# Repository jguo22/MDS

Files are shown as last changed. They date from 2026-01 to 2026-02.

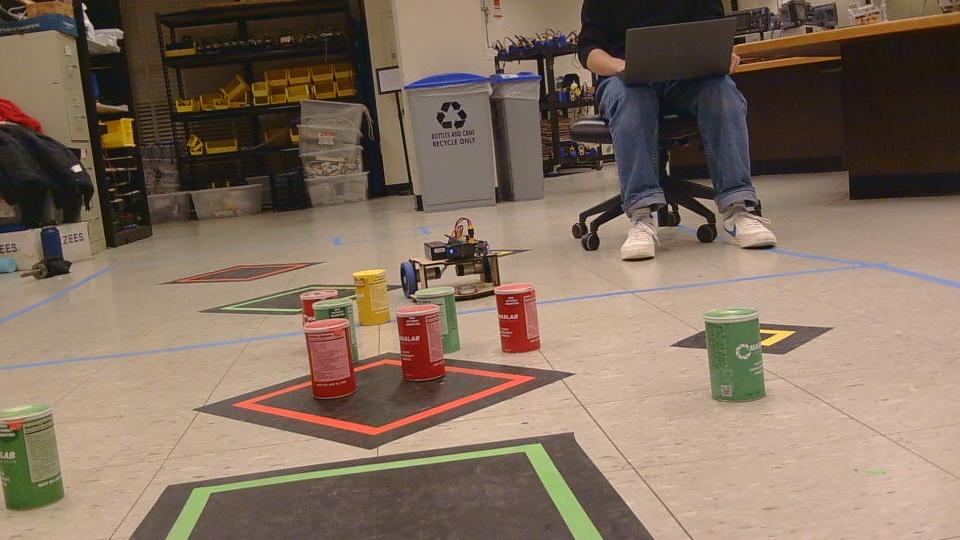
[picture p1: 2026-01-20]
vision/test2.jpg

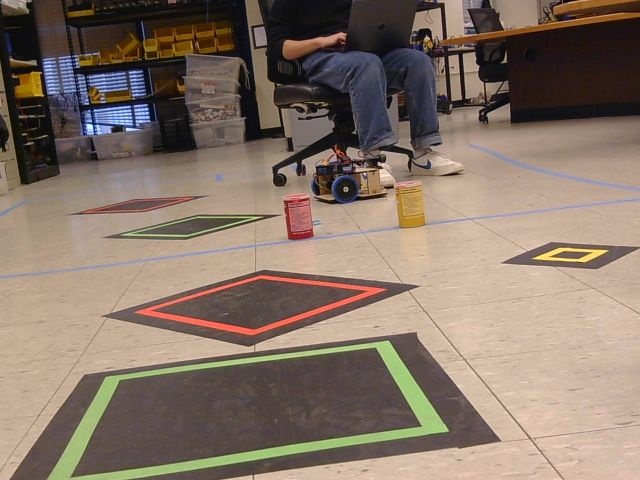
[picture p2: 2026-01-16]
vision/test.jpg

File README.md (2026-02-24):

# MASLAB 2026 Autonomous Robot
https://maslab.mit.edu/2026/wiki/team02

Autonomous can-collecting robot for the MIT MASLAB 2026 competition. Features dual-camera vision, YOLOv11 segmentation, path planning with Theta*, and a distributed architecture with Pi-side execution and computer-side control.

## Architecture

```
┌─────────────────────────────────────────────────────────────────────┐
│                          Computer                                    │
│  ┌─────────────────┐    ┌──────────────────┐    ┌────────────────┐  │
│  │ ComputerReceiver│◄───│  RobotHandler    │◄───│ Vision (YOLO)  │  │
│  │ (video in,      │    │  State Machine   │    │ Segmentation   │  │
│  │  commands out)  │    │  + Theta* Path   │    │ + Pixel-to-3D  │  │
│  └────────┬────────┘    └──────────────────┘    └────────────────┘  │
│           │                                                          │
│           │ TCP (video: 5000, commands: 5001)                        │
│           ▼                                                          │
│  ┌─────────────────┐                                                 │
│  │RemoteRobotCmd   │ ◄── IRobotCommander interface                   │
│  └─────────────────┘                                                 │
└─────────────────────────────────────────────────────────────────────┘
                              │
                              │ Network
                              ▼
┌─────────────────────────────────────────────────────────────────────┐
│                        Raspberry Pi                                  │
│  ┌─────────────────┐    ┌──────────────────┐    ┌────────────────┐  │
│  │  PiStreamer     │───►│ DirectRobotCmd   │───►│ Nav + Raven    │  │
│  │  (video out,    │    │ (local execution)│    │ Motor Control  │  │
│  │   commands in)  │    └──────────────────┘    └────────────────┘  │
│  └─────────────────┘                                                 │
│           │                                                          │
│           ▼                                                          │
│  ┌─────────────────┐    ┌──────────────────┐                        │
│  │  Dual Cameras   │    │  IMU + Distance  │                        │
│  │  (top + bottom) │    │  Sensors         │                        │
│  └─────────────────┘    └──────────────────┘                        │
└─────────────────────────────────────────────────────────────────────┘
```

## Quick Start

### Computer Side
```bash
# Install dependencies
pip install -e .

# Run computer receiver (waits for Pi connection)
python main_comp.py
```

### Pi Side
```bash
# Install dependencies
pip install -e .

# Run Pi streamer (auto-reconnects to computer)
python main_pi.py --camera-top /dev/videoblacktop --camera-bottom /dev/videoblackbot
```

## Project Structure

```
MDS/
├── main_comp.py              # Computer entry point (receiver + vision + state machine)
├── main_pi.py                # Pi entry point (streamer + command execution)
│
├── IRobotCommander.py        # Abstract interface for robot commands
├── RemoteRobotCommander.py   # Network implementation (computer side)
├── DirectRobotCommander.py   # Direct execution (Pi side)
│
├── RobotHandler.py           # Full state machine with zone/can tracking
├── RobotHandler_Simple.py    # Simplified state machine for basic collection
│
├── thetaStar.py              # Theta* path planning with obstacle avoidance
├── nav.py                    # Navigation controller (IMU + odometry)
├── navHelpers.py             # Movement command generators
│
├── raven.py                  # Raven motor controller driver
├── RavenWrapper.py           # High-level Raven interface (gripper, elevator)
├── IMUWrapper.py             # BNO08x IMU wrapper
├── distanceSensorWrapper.py  # Distance sensor for can approach
│
├── config.py                 # Robot configuration constants
├── colors.py                 # YOLO class names and color constants
├── getPickedCanColor.py      # Detect color of can in gripper
│
├── connection/               # Network communication
│   ├── ComputerReceiver.py   # Computer-side video receiver + command sender
│   ├── PiStreamer.py         # Pi-side video streamer + command receiver
│   ├── RemoteRobotCommander.py # Network command implementation
│   ├── protocol.py           # TCP message framing
│   ├── message_types.py      # Command type constants
│   ├── CameraCapture.py      # Camera interface
│   ├── FrameSaver.py         # Auto-save frames for debugging
│   └── frame_info.py         # Frame metadata structure
│
└── vision/                   # Vision processing (refactored)
    ├── segment.py            # YOLO segmentation entry point
    ├── mask_utils.py         # Mask processing (convex hull, HSV refinement)
    ├── can_utils.py          # Can detection + pixel-to-world transform
    ├── zone_utils.py         # Zone detection + quad extraction
    ├── pixelTo3D.py          # Camera calibration + ground plane projection
    ├── relativeCoordinates.py # SE2 coordinate transformations
    ├── calibration/          # Camera calibration tools
    ├── train/                # YOLO training scripts and datasets
    ├── best.pt               # Trained YOLO model
    └── yolo11n.pt            # Pretrained YOLO model
```

## Vision System

### YOLO Segmentation

Custom YOLOv11n model trained on 8 classes:
- `Boundary` (0), `Golden Can` (1), `Golden Zone` (2)
- `Green Can` (3), `Green Zone` (4), `Red Can` (5), `Red Zone` (6), `Robot` (7)

```python
from vision.segment import segmentImage
from vision.can_utils import getCans
from vision.zone_utils import getZones

result = segmentImage(image)  # Run YOLO segmentation
cans, can_classes = getCans(result, image, is_top=True)  # Get can positions (mm)
zones, zone_classes = getZones(result, image, is_top=True)  # Get zone quads (mm)
```

### Pixel-to-World Transformation

Transforms pixel coordinates to ground plane (mm) using camera calibration:

```python
from vision.pixelTo3D import transform_uv_to_xy

# pixel (u, v) -> world (x, y) in mm
x, y = transform_uv_to_xy(pixel_x, pixel_y, is_top=True)
```

### Coordinate Transformations

SE2-based world/relative coordinate conversion:

```python
from spatialmath import SE2
from vision.relativeCoordinates import world_to_relative, relative_to_world

robot_pose = SE2(robot_x, robot_y, robot_heading)
local_x, local_y = world_to_relative(world_point, robot_pose)
world_x, world_y = relative_to_world(local_point, robot_pose)
```

### Gripper Can Detection

Detect which color can is currently in the gripper:

```python
from getPickedCanColor import getPickedUpCanColor

color = getPickedUpCanColor(result, image)  # Returns 'Green Can', 'Red Can', etc.
```

## Robot Commander Interface

All robot commands go through `IRobotCommander`, with two implementations:

| Method | Description |
|---|---|
| `override_movement(args)` | Raw motor commands `[left, right, ticks, ...]` |
| `override_waypoints(args)` | Navigate through waypoints `[x1, y1, x2, y2, ...]` |
| `override_relative_xy(x, y)` | Move relative to robot (mm) |
| `override_world_xy(x, y)` | Navigate to world coordinates (mm) |
| `pickup_can()` | Close gripper + raise elevator |
| `set_down_can()` | Lower elevator + open gripper |
| `open_gripper()` | Open gripper only |
| `lower_elevator()` | Lower elevator only |
| `approach_can_with_ds()` | Approach can using distance sensor |
| `backup()` | Back up short distance |
| `stack(temp, stack, count)` | Stack can at position |
| `waitFinishedMoving()` | Block until movement complete |

## State Machines

### RobotHandler (Full)
Complex state machine with:
- Zone confidence tracking
- Can detection grid with thresholds
- Opponent zone avoidance
- Full early game strategy

### RobotHandler_Simple (Simplified)
Basic can collection:
```
SearchForCan -> MoveToCan -> ApproachingCan -> GrabCan -> MoveToZone -> Done
```

Configuration:
- `MAX_STACK`: Number of cans to collect before going to zone
- `target_zone`: Which zone to deliver to (GREEN_ZONE, RED_ZONE, GOLDEN_ZONE)
- `target_can_color`: Which color cans to collect

## Hardware

### Raven Motor Controller
Custom serial motor controller (460800 baud):
- 5 motor channels, 4 servo channels
- Position/velocity PID control
- Built-in odometry

### IMU (BNO08x)
- Must initialize before Raven board
- Heading relative to startup position

### Distance Sensor
- Used for precise can approach
- Target distance: 25mm, Max detection: 500mm

## Network Protocol

TCP-based with custom framing:
- Video port: 5000 (JPEG frames)
- Command port: 5001 (typed messages with float arrays)

Message types defined in `connection/message_types.py`:
```python
OVERRIDE_MOVEMENTS = 2      # [left, right, ticks, ...]
OVERRIDE_WAYPOINTS = 3      # [x1, y1, x2, y2, ...]
PICKUP_CAN = 4              # No args
RELEASE_CAN = 5             # No args
APPROACH_CAN_DS = 9         # No args
OPEN_GRIPPER = 15           # No args
LOWER_ELEVATOR = 16         # No args
# ... and more
```

## Configuration

Key constants in `config.py`:
```python
FRAME_WIDTH = 640
FRAME_HEIGHT = 480
FPS = 30

CAN_DIAMETER = 76.2         # mm
ROBOT_DIAMETER = 300        # mm
CLAW_OFFSET = 150           # mm from robot center
APPROACH_OFFSET = 200       # mm approach distance
```

## Development

### Testing Vision
```bash
# Test segmentation on image
python vision/segment.py

# Test can detection
python getPickedCanColor.py
```

### Training YOLO
```bash
cd vision/train
python train.py
```

### Debugging
- Frames auto-saved to `images/` with cooldown
- Telemetry streamed via `Streamer` class
- Profile data saved to `profiles/`

## Dependencies

See `pyproject.toml`:
- ultralytics (YOLO)
- opencv-python
- numpy
- spatialmath-python
- shapely
- adafruit-circuitpython-bno08x (Pi only)
- pyserial (Pi only)

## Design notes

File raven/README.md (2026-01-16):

# raven
Robot Hardware Controller

## Pcb
Color pallet works best with KiCad wDark theme

## Firmware
Built using cmake and all dependencies exist locally

Install build tools if you need to
```
sudo apt install ninja-build cmake gcc-arm-none-eabi
```

### Compiling
Compile from motor-hub folder
```
cmake . --preset=Release
cd Release
ninja
```

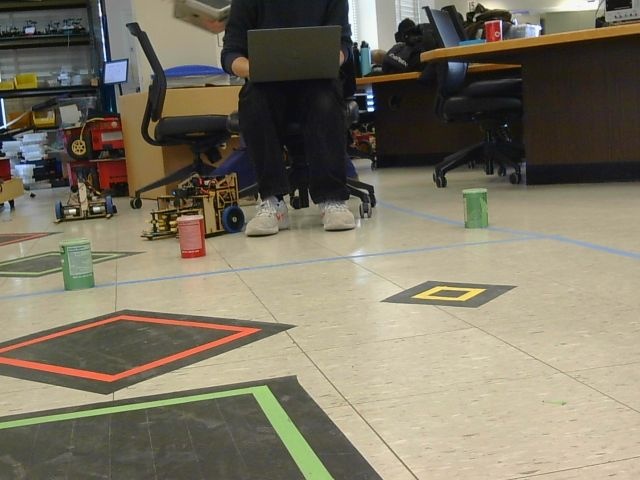
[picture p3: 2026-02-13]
images/frame_20260123_130812_1769191692037.jpg

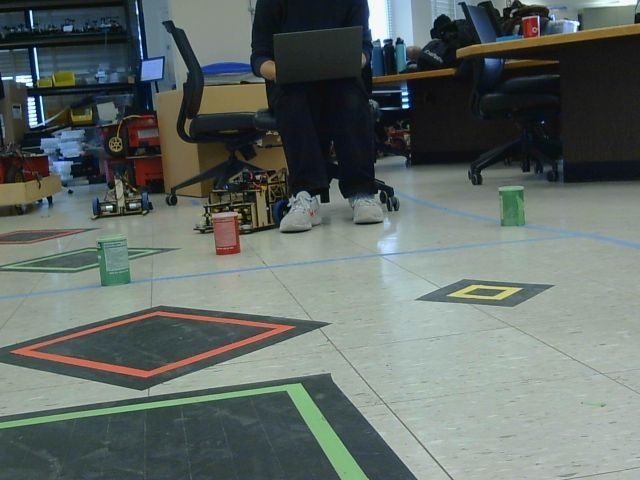
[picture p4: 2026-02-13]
images/frame_20260123_130701_1769191621960.jpg

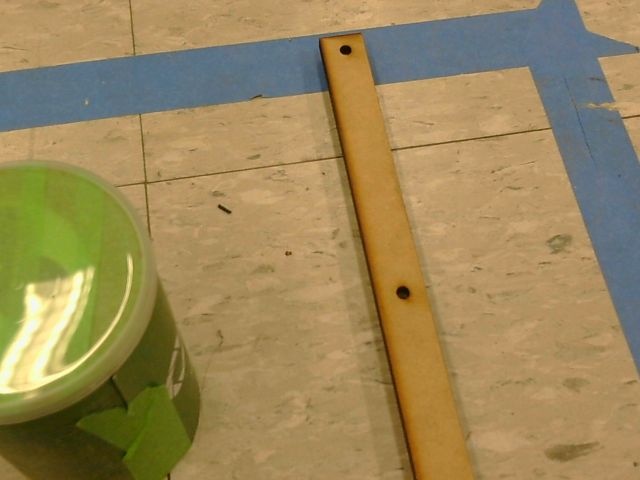
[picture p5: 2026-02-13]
images/frame_20260123_111651_1769185011692.jpg

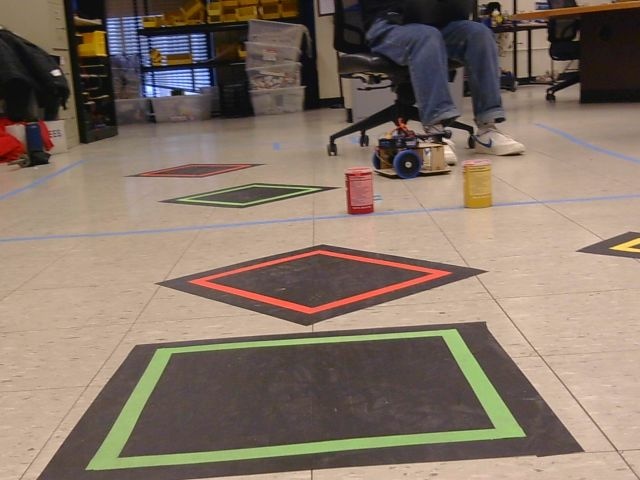
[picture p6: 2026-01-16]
images/frame_20260114_160316_1768424596912.jpg

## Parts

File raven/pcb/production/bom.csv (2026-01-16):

Designator | Footprint | Quantity | Value | LCSC Part #
C1 | C_Elec_8x6.2 | 1 | 100u | C178539
C10, C18, C30, C31, C34, C35, C36, C39, C7, C8 | 0402 | 10 | 100n | C1525
C11, C44 | 0402 | 2 | 220n | C16772
C12 | 0603 | 1 | 4u7 | C19666
C13, C50, C51, C52, C53, C54, C57, C58, C59, C60, C61, C62, C63, C64, C65 | 0805 | 15 | 22u | C45783
C14, C16, C19, C2, C21, C24, C26, C4, C66, C68 | 0402 | 10 | 100n | C307331
C15, C20, C25, C3, C6, C67, C9 | 0402 | 7 | 2u2 | C12530
C17, C22, C27, C5, C69 | 0402 | 5 | 22n | C1532
C23 | 0603 | 1 | 100n | C14663
C28 | 0603 | 1 | 10u | C96446
C32, C33 | 0402 | 2 | 12p | C1547
C37, C38, C46, C47, C48, C49 | 0402 | 6 | 1u | C52923
C40, C41, C42, C43 | 1206 | 4 | 47u | C96123
C45 | 0805 | 1 | 2u2 | C377773
C55 | 0402 | 1 | 10u | C15525
D1, D12, D14, D27, D3, D6, D9 | 0603 | 7 | GLED | C72043
D10, D13, D28, D4, D7 | 0603 | 5 | RLED | C2286
D11, D2, D26, D5, D8 | 0603 | 5 | WLED | C2290
F1 | 1206 | 1 | Fuse | C2838917
FB1 | 0805 | 1 | FerriteBead | C1017
J2, J5 | JST_SH_SM04B-SRSS-TB_1x04-1MP_P1.00mm_Horizontal | 2 | Conn_01x04_MountingPin | C160404
L1 | L_0660A | 1 | 1u | C18199443
Q1 | SOT-23 | 1 | AO3400A | C20917
Q3 | DMP2002UPS | 1 | DMP2002UPS | C154869
R1, R10, R11, R12, R13, R14, R15, R16, R17, R18, R19, R2, R20, R21, R22, R23, R27, R3, R4, R5, R50, R59, R6, R60, R61, R62, R63, R9 | 0402 | 28 | 1k | C11702
R24 | 0402 | 1 | 33k | C25779
R25, R26, R28, R29, R31, R33, R34, R35, R37, R39, R40, R41, R43, R49, R51, R52, R54, R55, R66, R7, R8 | 0402 | 21 | 7k5 | C25918
R53, R57 | 0402 | 2 | 56k | C25796
R56 | 0402 | 1 | 47k | C25792
R58 | 0402 | 1 | 100k | C25741
SW1, SW2 | TS-1088 | 2 | SW_Push | C720477
U1, U30, U4, U5, U6 | HTSSOP-16-1EP_4.4x5mm_P0.65mm_EP3.4x5mm_Mask2.46x2.31mm | 5 | DRV8874PWPR | C1855818
U2 | LGA-14_3x2.5mm_P0.5mm_LayoutBorder3x4y | 1 | ICM-42688-P | C1850418
U7 | QFN-48-1EP_7x7mm_P0.5mm_EP5.6x5.6mm | 1 | STM32G431CBUx | C529356
U8 | SOIC-16_3.9x9.9mm_P1.27mm | 1 | 74HC595 | C5947
U9 | TPS548B28RWWR | 1 | TPS548B28RWWR | C3188716
Y1 | Crystal_SMD_3225-4Pin_3.2x2.5mm | 1 | 16MHz | C13738

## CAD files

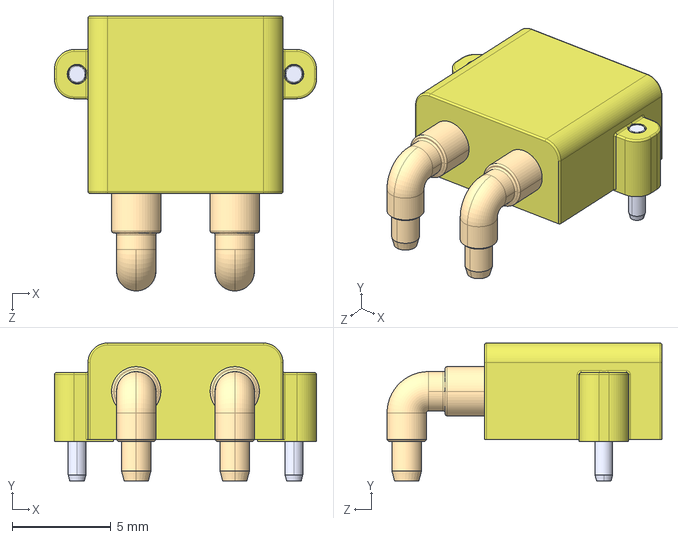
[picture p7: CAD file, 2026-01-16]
raven/pcb/3dmodels/XT30PW-M.STEP
13.3 x 7.00 x 14.0 mm

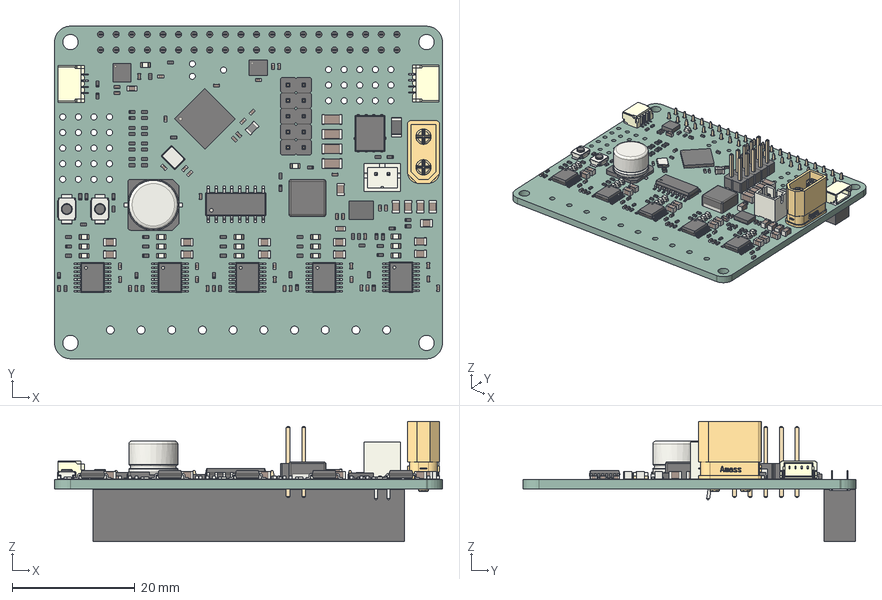
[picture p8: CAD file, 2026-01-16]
raven/pcb/raven.step
63.2 x 54.2 x 19.6 mm
L_Changjiang_FNR6028S
R_0402_1005Metric x 63
C_0402_1005Metric x 43
SOIC_16_39x99mm_P127mm
User Library-xt30upb-m
LED_0603_1608Metric x 17
PinHeader_1x02_P254mm_Vertical x 5
LGA_14_3x25mm_P05mm_LayoutBorder3x4y
C_0805_2012Metric x 16
C_1206_3216Metric x 4
C_0603_1608Metric x 2
QSOP_16_39x49mm_P0635mm x 5
Fuse_1206_3216Metric
LGA_16_3x3mm_P05mm
SM04B-SRSS-TB(LF)(SN) x 2
Crystal_SMD_3225-4Pin_3.2x2.5mm
SW_SPST_B3U-1000P-B x 2
RWW0021A_ASM
L_0805_2012Metric
Vishay_PowerPAK_SO-8
QFN-48-1EP_7x7mm_Pitch0.5mm
C_Elec_8x62
JST_B2B_PH_K
PinSocket_2x20_P2.54mm_Vertical
raven_PCB

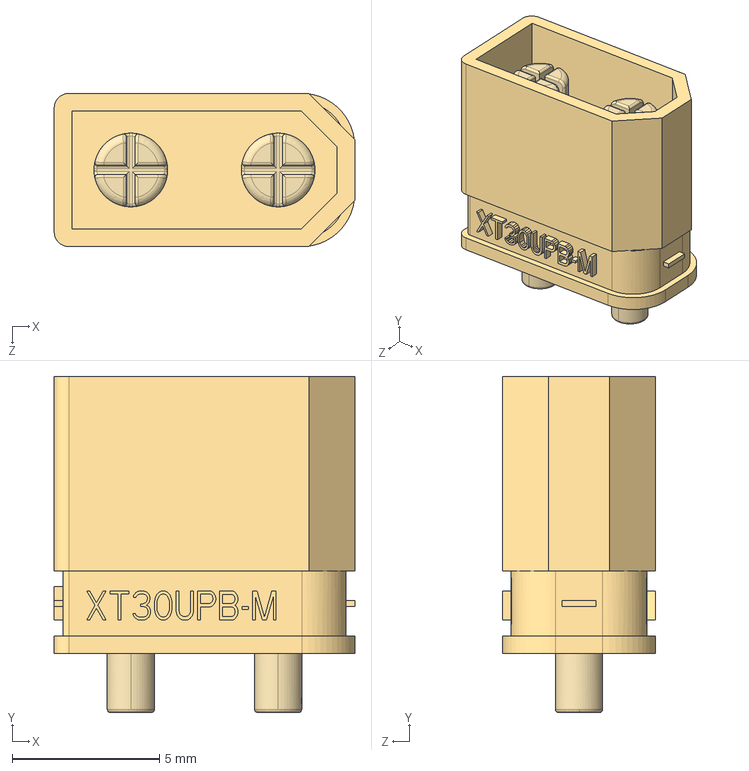
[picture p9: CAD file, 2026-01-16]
raven/pcb/3dmodels/XT30UPB-M.STEP
10.2 x 11.4 x 5.20 mm
XT30UPB-M
XT30UPB-M-PIN x 2

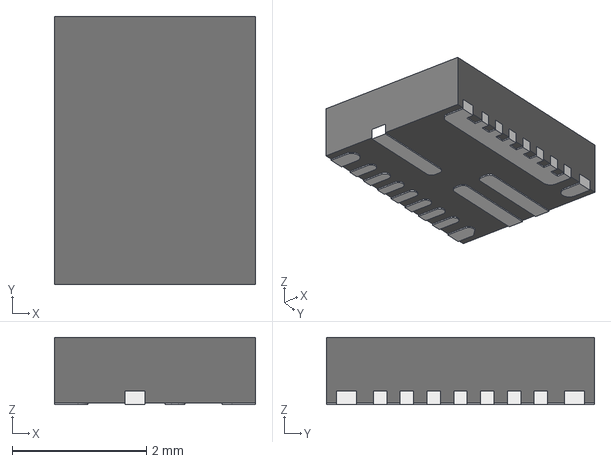
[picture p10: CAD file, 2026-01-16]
raven/pcb/3dmodels/RWW0021A.STEP
3.00 x 4.00 x 1.00 mm
FRAME
MOLD

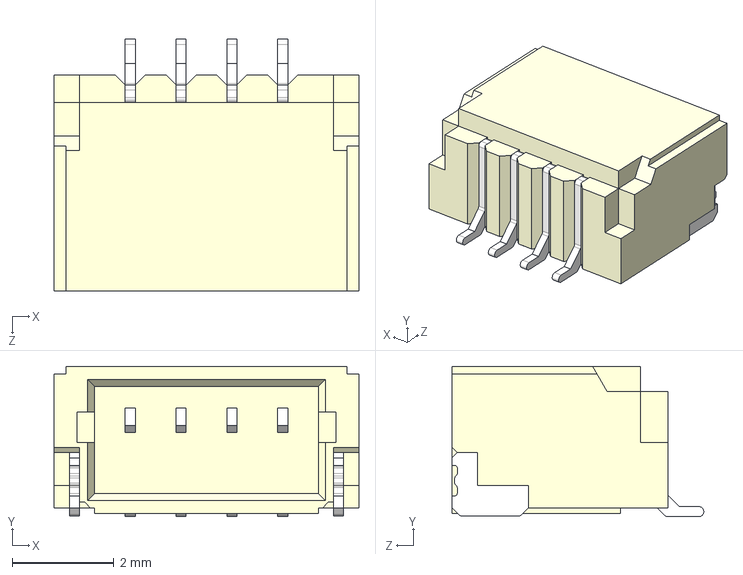
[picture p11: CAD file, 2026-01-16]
raven/pcb/3dmodels/SM04B-SRSS-TB.STEP
6.00 x 2.96 x 4.95 mm

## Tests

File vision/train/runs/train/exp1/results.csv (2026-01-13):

epoch | time | train/box_loss | train/cls_loss | train/dfl_loss | metrics/precision(B) | metrics/recall(B) | metrics/mAP50(B) | metrics/mAP50-95(B) | val/box_loss | val/cls_loss | val/dfl_loss | lr/pg0 | lr/pg1 | lr/pg2
1 | 5.62403 | 0.70651 | 3.71754 | 0.99922 | 0.00399 | 0.61548 | 0.04409 | 0.02615 | 0.58543 | 3.50993 | 0.94233 | 0.0002 | 0.0002 | 0.0002
2 | 11.2085 | 0.60502 | 3.71149 | 0.94844 | 0.00429 | 0.65714 | 0.05756 | 0.03691 | 0.48434 | 3.47711 | 0.91924 | 0.000499984 | 0.000499984 | 0.000499984
3 | 16.8646 | 0.61432 | 3.49701 | 0.9548 | 0.00459 | 0.69881 | 0.10148 | 0.07609 | 0.42329 | 3.44849 | 0.90228 | 0.000799947 | 0.000799947 | 0.000799947
4 | 22.1051 | 0.63108 | 3.55089 | 0.98978 | 0.00514 | 0.7881 | 0.1724 | 0.1499 | 0.47095 | 3.42675 | 0.9275 | 0.00109989 | 0.00109989 | 0.00109989
5 | 27.1586 | 0.55508 | 3.48892 | 0.91688 | 0.00492 | 0.74881 | 0.16782 | 0.14527 | 0.45083 | 3.40929 | 0.89888 | 0.00139982 | 0.00139982 | 0.00139982
6 | 32.1116 | 0.53779 | 3.28165 | 0.92975 | 0.00577 | 0.87143 | 0.17461 | 0.15685 | 0.4217 | 3.38585 | 0.88139 | 0.00169972 | 0.00169972 | 0.00169972
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

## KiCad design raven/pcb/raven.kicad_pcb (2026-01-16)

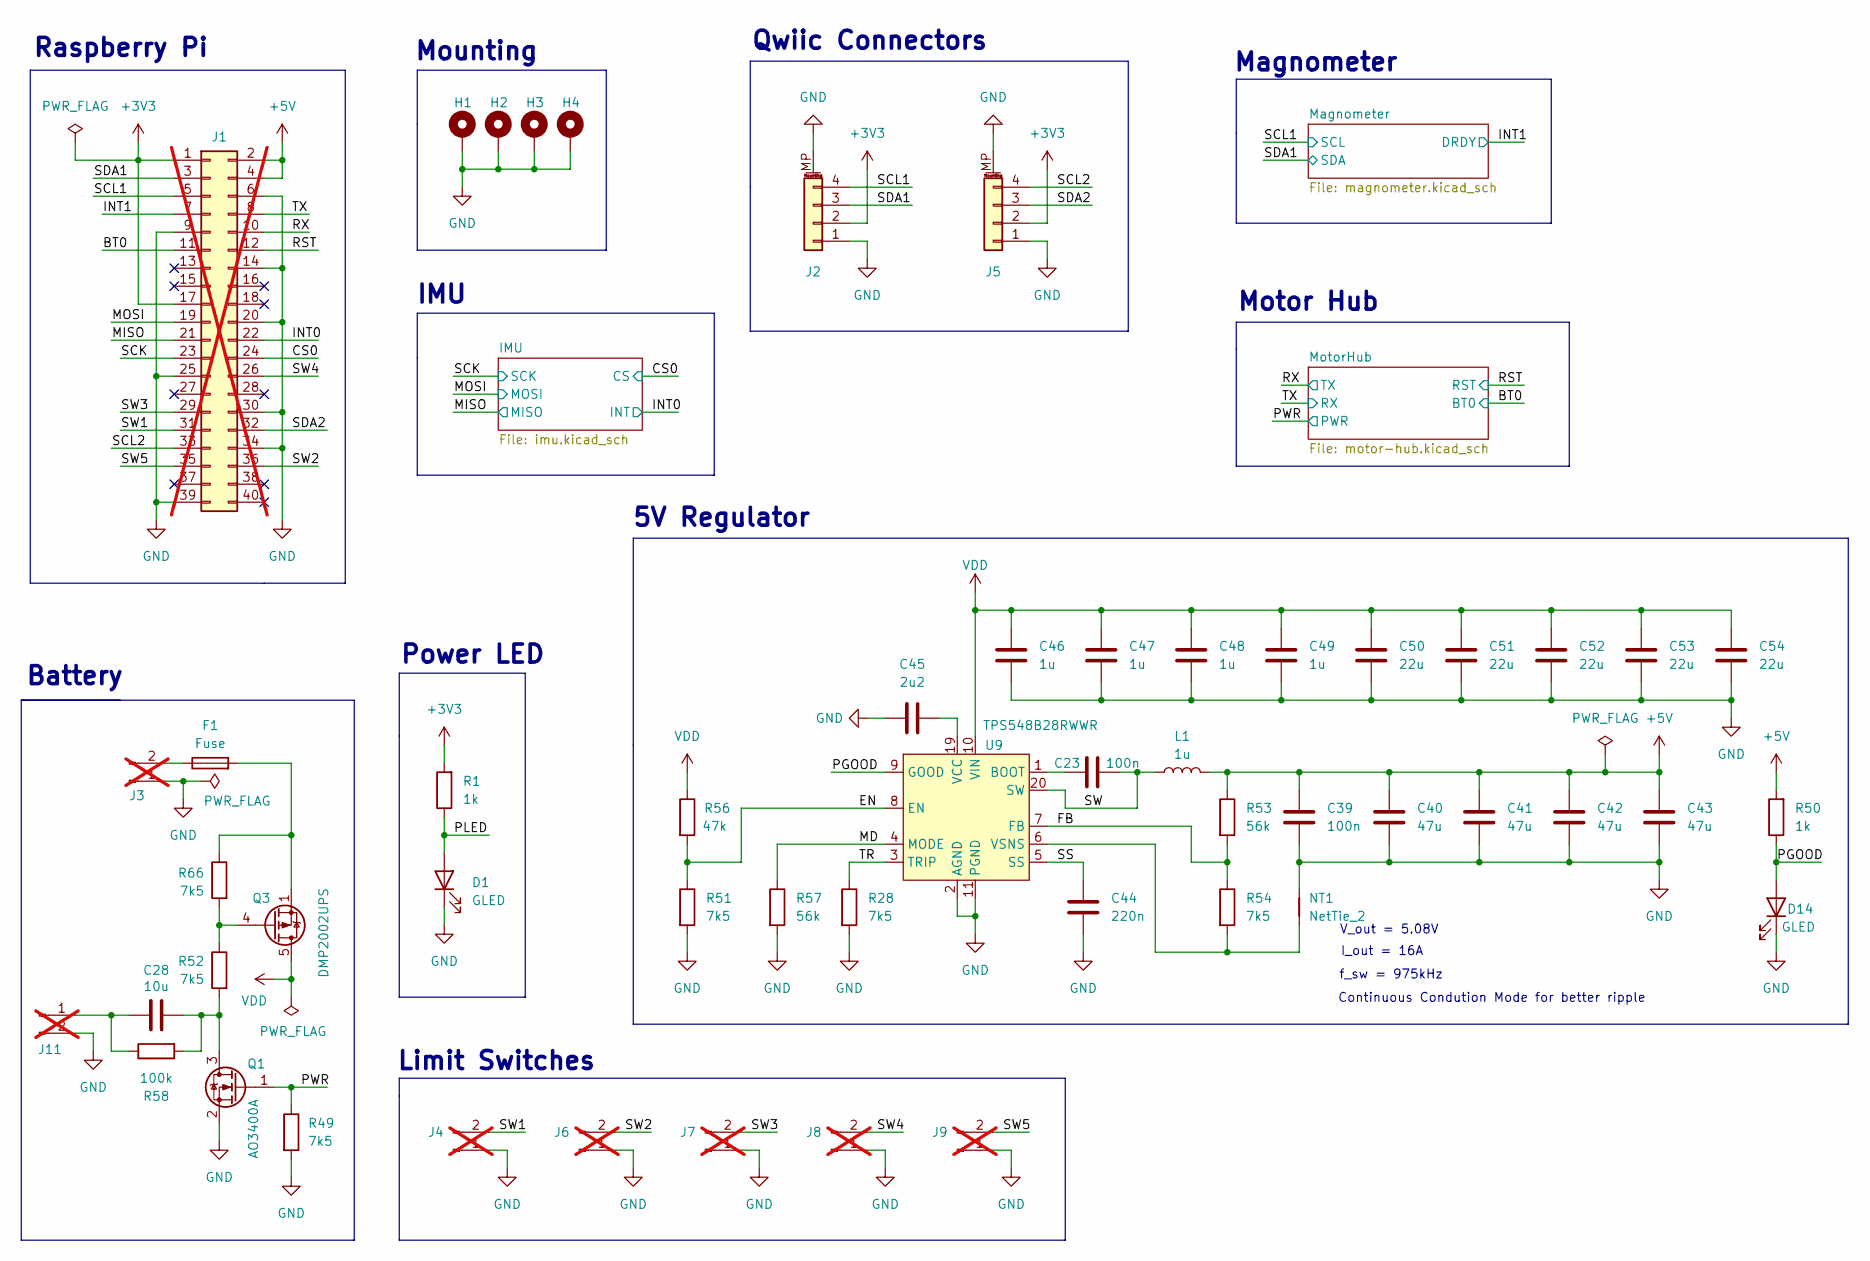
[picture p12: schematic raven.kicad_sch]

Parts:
C23: 100n; C_0603_1608Metric; LCSC C14663
C28: 10u; C_0603_1608Metric; LCSC C96446
C39: 100n; C_0402_1005Metric; LCSC C1525
C40, C41, C42, C43: 47u; C_1206_3216Metric; LCSC C96123
C44: 220n; C_0402_1005Metric; LCSC C16772
C45: 2u2; C_0805_2012Metric; LCSC C377773
C46, C47, C48, C49: 1u; C_0402_1005Metric; LCSC C52923
C50, C51, C52, C53, C54: 22u; C_0805_2012Metric; LCSC C45783
D1, D14: GLED; LED_0603_1608Metric; LCSC C72043
F1: Fuse; Fuse_1206_3216Metric; LCSC C2838917
H1, H2, H3, H4: MountingHole_Pad; MountingHole_2.5mm_Pad
J1: Conn_02x20_Odd_Even; PinSocket_2x20_P2.54mm_Vertical; LCSC C35165; not fitted
J2, J5: Conn_01x04_MountingPin; JST_SH_SM04B-SRSS-TB_1x04-1MP_P1.00mm_Horizontal; LCSC C160404
J3: Conn_01x02_Pin; AMASS_XT30UPB-M_1x02_P5.0mm_Vertical; LCSC C428721; not fitted
J4, J6, J7, J8, J9: Conn_01x02_Pin; PinHeader_1x02_P2.54mm_Vertical; LCSC C492401; not fitted
J11: Conn_01x02_Pin; JST_PH_B2B-PH-K_1x02_P2.00mm_Vertical; LCSC C131337; not fitted
L1: 1u; L_0660A; LCSC C18199443
NT1: NetTie_2; NetTie-2_SMD_Pad0.5mm
Q1: AO3400A; SOT-23; LCSC C20917
Q3: DMP2002UPS; LCSC C154869
R1, R50: 1k; R_0402_1005Metric; LCSC C11702
R28, R49, R51, R52, R54, R66: 7k5; R_0402_1005Metric; LCSC C25918
R53, R57: 56k; R_0402_1005Metric; LCSC C25796
R56: 47k; R_0402_1005Metric; LCSC C25792
R58: 100k; R_0402_1005Metric; LCSC C25741
U9: TPS548B28RWWR; LCSC C3188716

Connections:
+3V3: J1.1, J1.17, J2.2, J5.2, R1.2; also elsewhere on the board
+5V: C39.2, C40.1, C41.1, C42.1, C43.1, J1.2, J1.4, L1.2, R50.2, R53.1; also elsewhere on the board
/BT0: J1.11; also elsewhere on the board
/CS0: J1.24; also elsewhere on the board
/EN: R51.1, R56.2, U9.8 (EN)
/FB: R53.2, R54.1, U9.7 (FB)
/INT0: J1.22; also elsewhere on the board
/INT1: J1.7; also elsewhere on the board
/MD: R57.1, U9.4 (MODE)
/MISO: J1.21; also elsewhere on the board
/MOSI: J1.19; also elsewhere on the board
/PGOOD: D14.2 (A), R50.1, U9.9 (GOOD)
/PLED: D1.2 (A), R1.1
/PWR: Q1.1 (G), R49.1; also elsewhere on the board
/RST: J1.12; also elsewhere on the board
/RX: J1.10; also elsewhere on the board
/SCK: J1.23; also elsewhere on the board
/SCL1: J1.5, J2.4; also elsewhere on the board
/SCL2: J1.33, J5.4
/SDA1: J1.3, J2.3; also elsewhere on the board
/SDA2: J1.32, J5.3
/SS: C44.1, U9.5 (SS)
/SW: C23.2, L1.1, U9.20 (SW)
/SW1: J1.31, J4.2
/SW2: J1.36, J6.2
/SW3: J1.29, J7.2
/SW4: J1.26, J8.2
/SW5: J1.35, J9.2
/TR: R28.1, U9.3 (TRIP)
/TX: J1.8; also elsewhere on the board
GND: C39.1, C40.2, C41.2, C42.2, C43.2, C44.2, C45.1, C46.2, C47.2, C48.2, C49.2, C50.2, C51.2, C52.2, C53.2, C54.2, D1.1 (K), D14.1 (K), H1.1, H2.1, H3.1, H4.1, J1.6, J1.9, J1.14, J1.20, J1.25, J1.30, J1.34, J1.39, J2.1, J2.MP (MountPin), J3.1, J4.1, J5.1, J5.MP (MountPin), J6.1, J7.1, J8.1, J9.1, J11.2, NT1.1, Q1.2 (S), R28.2, R49.2, R51.2, R57.2, U9.2 (AGND), U9.11 (PGND), U9.12 (PGND), U9.13 (PGND), U9.14 (PGND), U9.15 (PGND), U9.16 (PGND), U9.17 (PGND), U9.18 (PGND); also elsewhere on the board
unnamed: F1.2, Q3.1 (S), Q3.2 (S), Q3.3 (S), R66.1
unnamed: F1.1, J3.2
unnamed: C28.1, J11.1, R58.1
unnamed: C28.2, Q1.3 (D), R52.2, R58.2
unnamed: Q3.4 (G), R52.1, R66.2
unnamed: C23.1, U9.1 (BOOT)
unnamed: C45.2, U9.19 (VCC)
unnamed: NT1.2, R54.2, U9.6 (VSNS)
VDD: C46.1, C47.1, C48.1, C49.1, C50.1, C51.1, C52.1, C53.1, C54.1, Q3.5 (D), Q3.6 (D), Q3.7 (D), Q3.8 (D), R56.1, U9.10 (VIN), U9.21 (VIN); also elsewhere on the board

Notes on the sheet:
Mounting
Power LED
5V Regulator
IMU
Motor Hub
V_out = 5.08V
Limit Switches
Continuous Condution Mode for better ripple
Qwiic Connectors
Battery
I_out = 16A
f_sw = 975kHz
Raspberry Pi
Magnometer

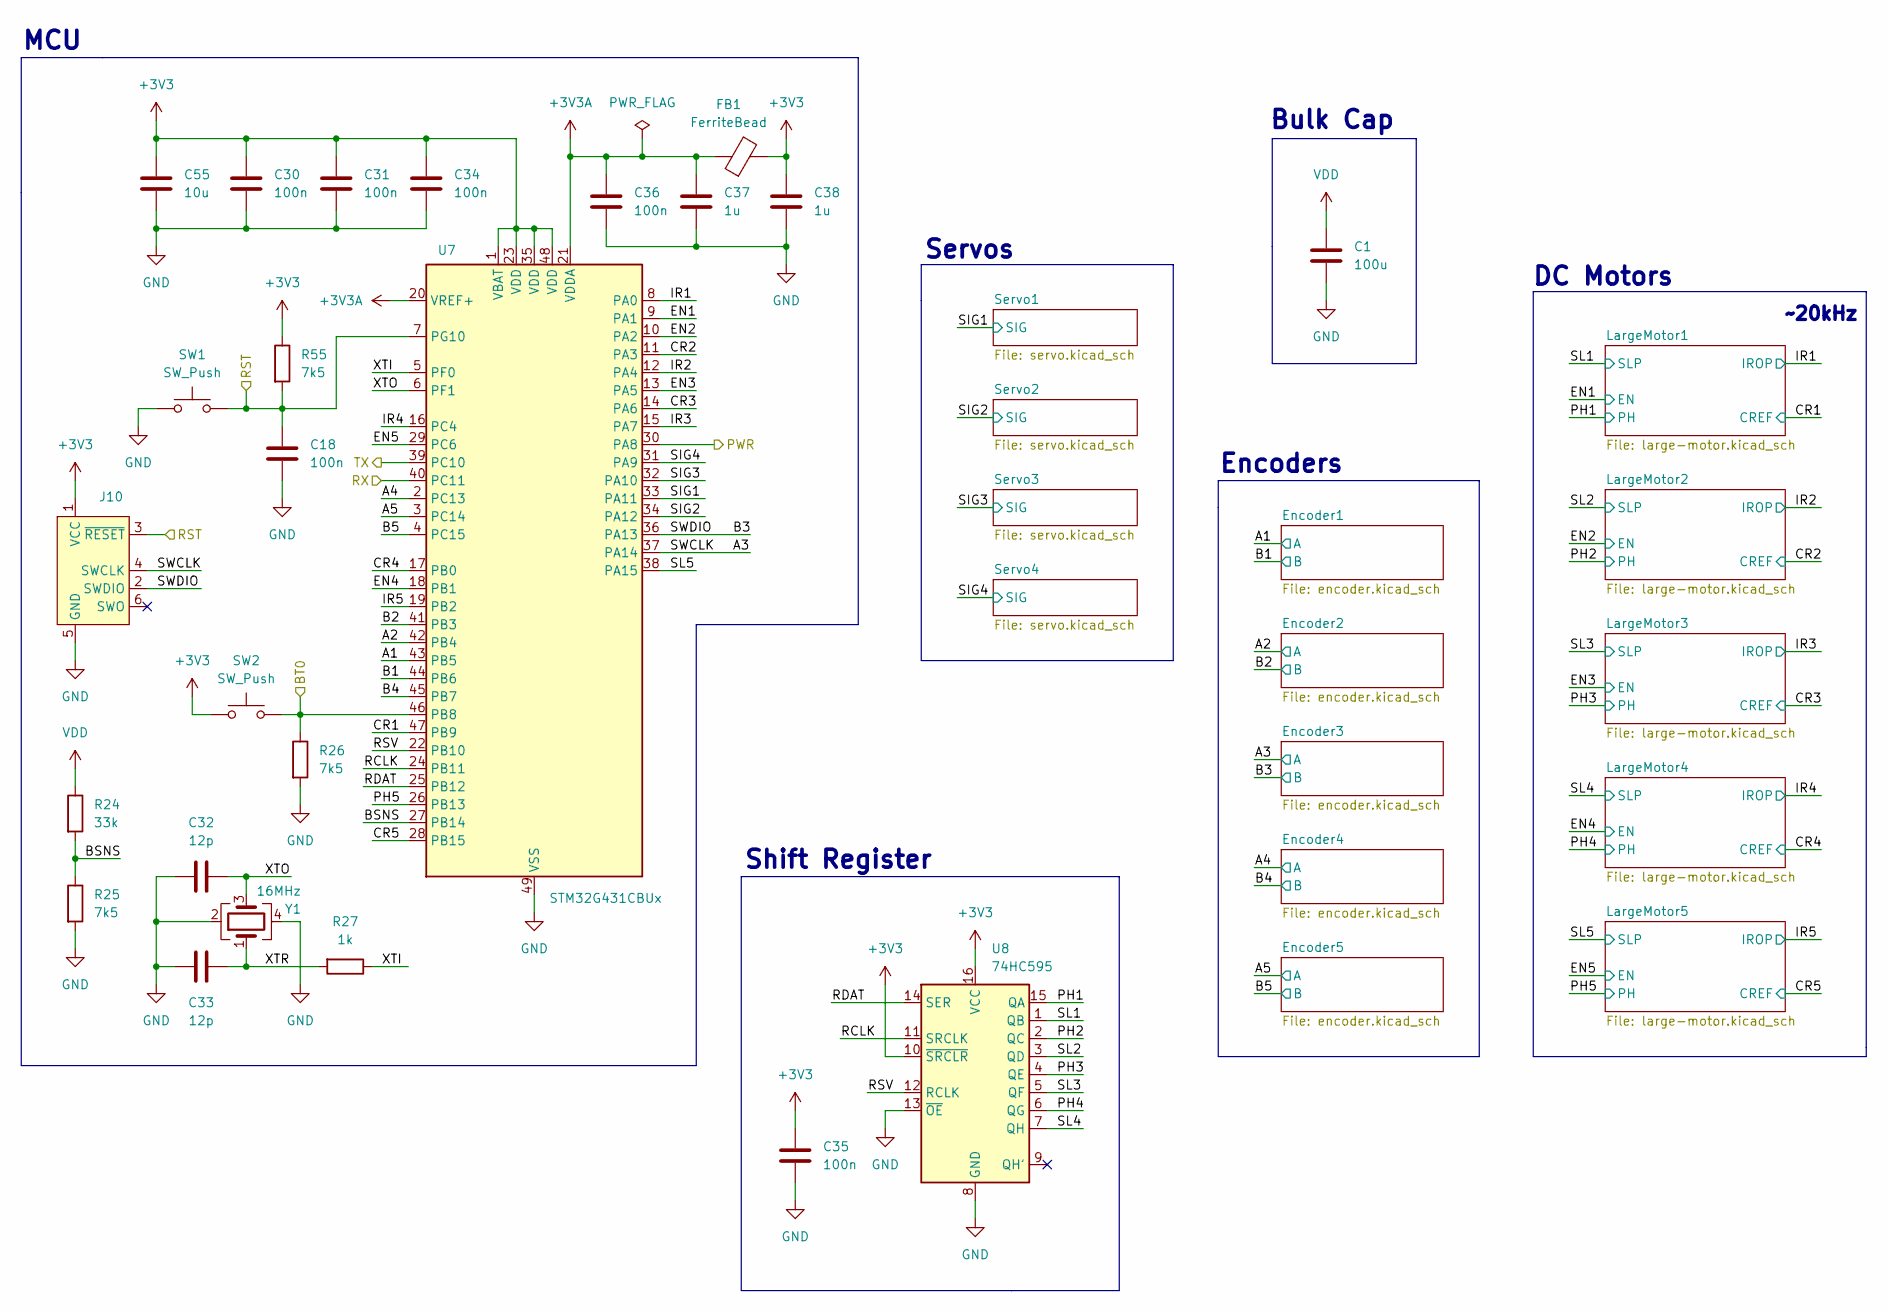
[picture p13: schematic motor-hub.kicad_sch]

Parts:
C1: 100u; C_Elec_8x6.2; LCSC C178539
C18, C30, C31, C34, C35, C36: 100n; C_0402_1005Metric; LCSC C1525
C32, C33: 12p; C_0402_1005Metric; LCSC C1547
C37, C38: 1u; C_0402_1005Metric; LCSC C52923
C55: 10u; C_0402_1005Metric; LCSC C15525
FB1: FerriteBead; L_0805_2012Metric; LCSC C1017
J10: Conn_ARM_SWD_TagConnect_TC2030-NL; Tag-Connect_TC2030-IDC-NL_2x03_P1.27mm_Vertical
R24: 33k; R_0402_1005Metric; LCSC C25779
R25, R26, R55: 7k5; R_0402_1005Metric; LCSC C25918
R27: 1k; R_0402_1005Metric; LCSC C11702
SW1, SW2: SW_Push; TS-1088; LCSC C720477
U7: STM32G431CBUx; QFN-48-1EP_7x7mm_P0.5mm_EP5.6x5.6mm; LCSC C529356
U8: 74HC595; SOIC-16_3.9x9.9mm_P1.27mm; LCSC C5947
Y1: 16MHz; Crystal_SMD_3225-4Pin_3.2x2.5mm; LCSC C13738

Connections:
+3V3: C30.1, C31.1, C34.1, C35.1, C38.1, C55.1, FB1.2, J10.1 (VCC), R55.1, SW2.1, U7.1 (VBAT), U7.23 (VDD), U7.35 (VDD), U7.48 (VDD), U8.10 (~SRCLR), U8.16 (VCC); also elsewhere on the board
+3V3A: C36.1, C37.1, FB1.1, U7.20 (VREF+), U7.21 (VDDA)
/BT0: R26.1, SW2.2, U7.46 (PB8); also elsewhere on the board
/MotorHub/A1: U7.43 (PB5); also elsewhere on the board
/MotorHub/A2: U7.42 (PB4); also elsewhere on the board
/MotorHub/A3: J10.4 (SWCLK), U7.37 (PA14); also elsewhere on the board
/MotorHub/A4: U7.2 (PC13); also elsewhere on the board
/MotorHub/A5: U7.3 (PC14); also elsewhere on the board
/MotorHub/B1: U7.44 (PB6); also elsewhere on the board
/MotorHub/B2: U7.41 (PB3); also elsewhere on the board
/MotorHub/B3: J10.2 (SWDIO), U7.36 (PA13); also elsewhere on the board
/MotorHub/B4: U7.45 (PB7); also elsewhere on the board
/MotorHub/B5: U7.4 (PC15); also elsewhere on the board
/MotorHub/BSNS: R24.2, R25.1, U7.27 (PB14)
/MotorHub/CR1: U7.47 (PB9); also elsewhere on the board
/MotorHub/CR2: U7.11 (PA3); also elsewhere on the board
/MotorHub/CR3: U7.14 (PA6); also elsewhere on the board
/MotorHub/CR4: U7.17 (PB0); also elsewhere on the board
/MotorHub/CR5: U7.28 (PB15); also elsewhere on the board
/MotorHub/EN1: U7.9 (PA1); also elsewhere on the board
/MotorHub/EN2: U7.10 (PA2); also elsewhere on the board
/MotorHub/EN3: U7.13 (PA5); also elsewhere on the board
/MotorHub/EN4: U7.18 (PB1); also elsewhere on the board
/MotorHub/EN5: U7.29 (PC6); also elsewhere on the board
/MotorHub/IR1: U7.8 (PA0); also elsewhere on the board
/MotorHub/IR2: U7.12 (PA4); also elsewhere on the board
/MotorHub/IR3: U7.15 (PA7); also elsewhere on the board
/MotorHub/IR4: U7.16 (PC4); also elsewhere on the board
/MotorHub/IR5: U7.19 (PB2); also elsewhere on the board
/MotorHub/PH1: U8.15 (QA); also elsewhere on the board
/MotorHub/PH2: U8.2 (QC); also elsewhere on the board
/MotorHub/PH3: U8.4 (QE); also elsewhere on the board
/MotorHub/PH4: U8.6 (QG); also elsewhere on the board
/MotorHub/PH5: U7.26 (PB13); also elsewhere on the board
/MotorHub/RCLK: U7.24 (PB11), U8.11 (SRCLK)
/MotorHub/RDAT: U7.25 (PB12), U8.14 (SER)
/MotorHub/RSV: U7.22 (PB10), U8.12 (RCLK)
/MotorHub/SIG1: U7.33 (PA11); also elsewhere on the board
/MotorHub/SIG2: U7.34 (PA12); also elsewhere on the board
/MotorHub/SIG3: U7.32 (PA10); also elsewhere on the board
/MotorHub/SIG4: U7.31 (PA9); also elsewhere on the board
/MotorHub/SL1: U8.1 (QB); also elsewhere on the board
/MotorHub/SL2: U8.3 (QD); also elsewhere on the board
/MotorHub/SL3: U8.5 (QF); also elsewhere on the board
/MotorHub/SL4: U8.7 (QH); also elsewhere on the board
/MotorHub/SL5: U7.38 (PA15); also elsewhere on the board
/MotorHub/XTI: R27.1, U7.5 (PF0)
/MotorHub/XTO: C32.2, U7.6 (PF1), Y1.3
/MotorHub/XTR: C33.2, R27.2, Y1.1
/PWR: U7.30 (PA8); also elsewhere on the board
/RST: C18.1, J10.3 (~RESET), R55.2, SW1.2, U7.7 (PG10); also elsewhere on the board
/RX: U7.39 (PC10); also elsewhere on the board
/TX: U7.40 (PC11); also elsewhere on the board
GND: C1.2, C18.2, C30.2, C31.2, C32.1, C33.1, C34.2, C35.2, C36.2, C37.2, C38.2, C55.2, J10.5 (GND), R25.2, R26.2, SW1.1, U7.49 (VSS), U8.8 (GND), U8.13 (~OE), Y1.2, Y1.4; also elsewhere on the board
VDD: C1.1, R24.1; also elsewhere on the board

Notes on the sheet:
~20kHz
Bulk Cap
Servos
MCU
DC Motors
Encoders
Shift Register

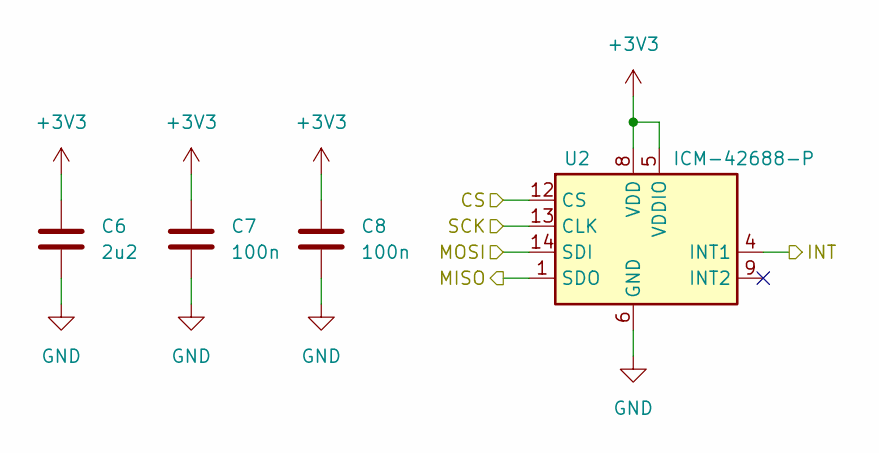
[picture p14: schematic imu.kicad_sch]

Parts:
C6: 2u2; C_0402_1005Metric; LCSC C12530
C7, C8: 100n; C_0402_1005Metric; LCSC C1525
U2: ICM-42688-P; LGA-14_3x2.5mm_P0.5mm_LayoutBorder3x4y; LCSC C1850418

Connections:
+3V3: C6.1, C7.1, C8.1, U2.5 (VDDIO), U2.8 (VDD); also elsewhere on the board
/CS0: U2.12 (CS); also elsewhere on the board
/INT0: U2.4 (INT1); also elsewhere on the board
/MISO: U2.1 (SDO); also elsewhere on the board
/MOSI: U2.14 (SDI); also elsewhere on the board
/SCK: U2.13 (CLK); also elsewhere on the board
GND: C6.2, C7.2, C8.2, U2.6 (GND), U2.7 (RESV), U2.11 (RESV); also elsewhere on the board

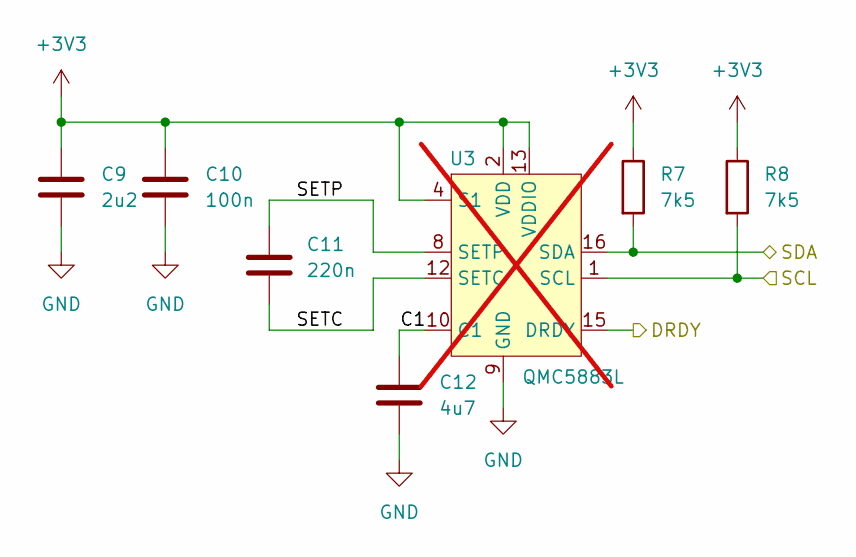
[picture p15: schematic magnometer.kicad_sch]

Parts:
C9: 2u2; C_0402_1005Metric; LCSC C12530
C10: 100n; C_0402_1005Metric; LCSC C1525
C11: 220n; C_0402_1005Metric; LCSC C16772
C12: 4u7; C_0603_1608Metric; LCSC C19666
R7, R8: 7k5; R_0402_1005Metric; LCSC C25918
U3: QMC5883L; LGA-16_3x3mm_P0.5mm; not fitted

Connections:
+3V3: C9.1, C10.1, R7.1, R8.1, U3.2 (VDD), U3.4 (S1), U3.13 (VDDIO); also elsewhere on the board
/INT1: U3.15 (DRDY); also elsewhere on the board
/Magnometer/C1: C12.1, U3.10 (C1)
/Magnometer/SETC: C11.2, U3.12 (SETC)
/Magnometer/SETP: C11.1, U3.8 (SETP)
/SCL1: R8.2, U3.1 (SCL); also elsewhere on the board
/SDA1: R7.2, U3.16 (SDA); also elsewhere on the board
GND: C9.2, C10.2, C12.2, U3.9 (GND), U3.11 (GND); also elsewhere on the board

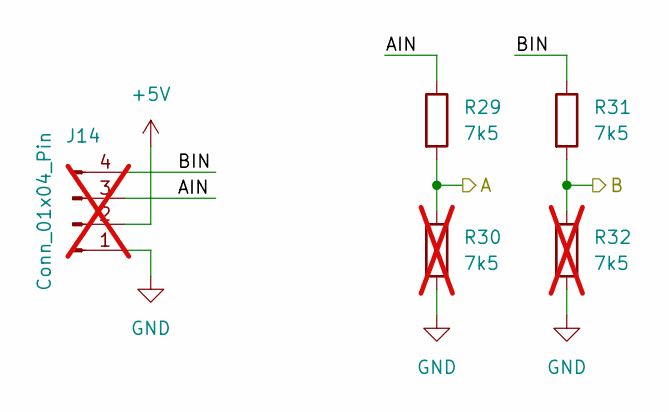
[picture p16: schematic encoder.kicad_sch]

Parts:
J14: Conn_01x04_Pin; PinHeader_1x04_P2.54mm_Vertical; LCSC C6332197; not fitted
R29, R31: 7k5; R_0402_1005Metric; LCSC C25918
R30, R32: 7k5; R_0402_1005Metric; LCSC C25918; not fitted

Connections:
+5V: J14.2; also elsewhere on the board
/MotorHub/A1: R29.2, R30.1; also elsewhere on the board
/MotorHub/B1: R31.2, R32.1; also elsewhere on the board
/MotorHub/Encoder1/AIN: J14.3, R29.1
/MotorHub/Encoder1/BIN: J14.4, R31.1
GND: J14.1, R30.2, R32.2; also elsewhere on the board

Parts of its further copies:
J15, J16, J17, J18: Conn_01x04_Pin; PinHeader_1x04_P2.54mm_Vertical; LCSC C6332197; not fitted
R33, R34, R35, R37, R39, R40, R41, R43: 7k5; R_0402_1005Metric; LCSC C25918
R36, R38, R42, R44, R45, R46, R47, R48: 7k5; R_0402_1005Metric; LCSC C25918; not fitted

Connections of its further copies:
+5V: J15.2, J16.2, J17.2, J18.2; also elsewhere on the board
/MotorHub/A2: R33.2, R36.1; also elsewhere on the board
/MotorHub/A3: R34.2, R42.1; also elsewhere on the board
/MotorHub/A4: R35.2, R47.1; also elsewhere on the board
/MotorHub/A5: R39.2, R48.1; also elsewhere on the board
/MotorHub/B2: R37.2, R38.1; also elsewhere on the board
/MotorHub/B3: R40.2, R44.1; also elsewhere on the board
/MotorHub/B4: R41.2, R45.1; also elsewhere on the board
/MotorHub/B5: R43.2, R46.1; also elsewhere on the board
/MotorHub/Encoder2/AIN: J15.3, R33.1
/MotorHub/Encoder2/BIN: J15.4, R37.1
/MotorHub/Encoder3/AIN: J16.3, R34.1
/MotorHub/Encoder3/BIN: J16.4, R40.1
/MotorHub/Encoder4/AIN: J17.3, R35.1
/MotorHub/Encoder4/BIN: J17.4, R41.1
/MotorHub/Encoder5/AIN: J18.3, R39.1
/MotorHub/Encoder5/BIN: J18.4, R43.1
GND: J15.1, J16.1, J17.1, J18.1, R36.2, R38.2, R42.2, R44.2, R45.2, R46.2, R47.2, R48.2; also elsewhere on the board

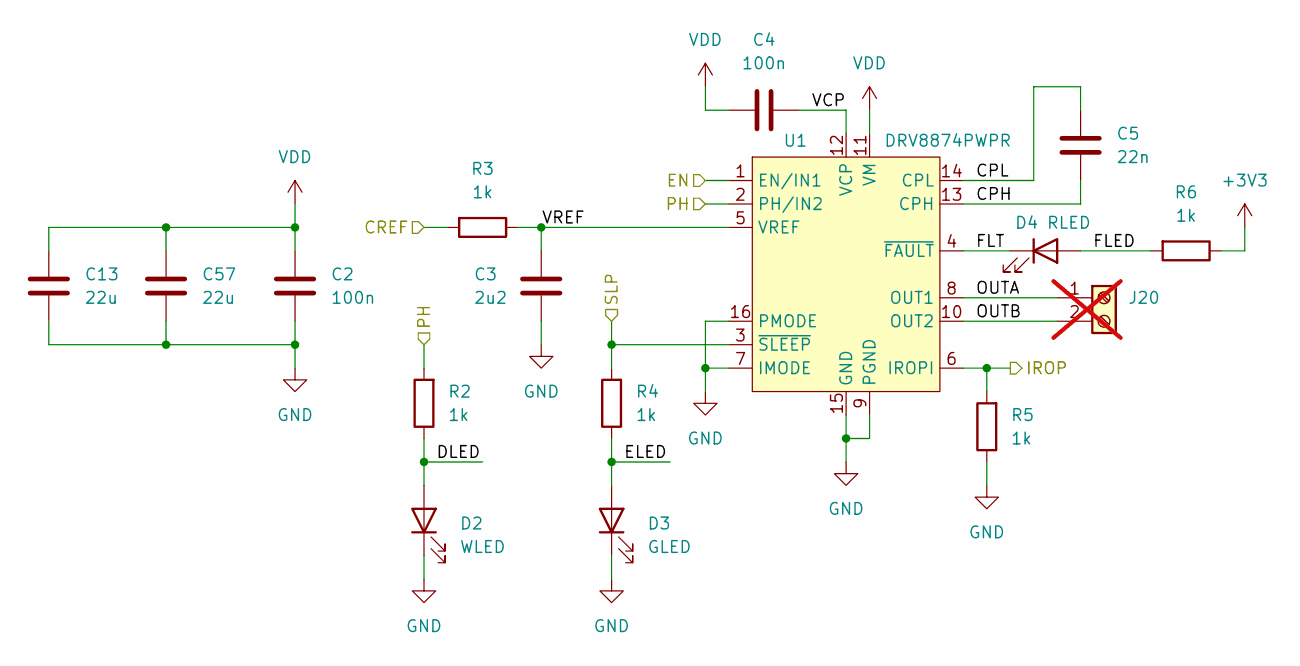
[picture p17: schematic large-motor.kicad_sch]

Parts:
C2, C4: 100n; C_0402_1005Metric; LCSC C307331
C3: 2u2; C_0402_1005Metric; LCSC C12530
C5: 22n; C_0402_1005Metric; LCSC C1532
C13, C57: 22u; C_0805_2012Metric; LCSC C45783
D2: WLED; LED_0603_1608Metric; LCSC C2290
D3: GLED; LED_0603_1608Metric; LCSC C72043
D4: RLED; LED_0603_1608Metric; LCSC C2286
J20: Screw_Terminal_01x02; TerminalBlock_Phoenix_MKDS-1,5-2_1x02_P5.00mm_Horizontal; LCSC C8404; not fitted
R2, R3, R4, R5, R6: 1k; R_0402_1005Metric; LCSC C11702
U1: DRV8874PWPR; HTSSOP-16-1EP_4.4x5mm_P0.65mm_EP3.4x5mm_Mask2.46x2.31mm; LCSC C1855818

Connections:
+3V3: R6.1; also elsewhere on the board
/MotorHub/CR2: R3.2; also elsewhere on the board
/MotorHub/EN2: U1.1 (EN/IN1); also elsewhere on the board
/MotorHub/IR2: R5.2, U1.6 (IROPI); also elsewhere on the board
/MotorHub/LargeMotor2/CPH: C5.2, U1.13 (CPH)
/MotorHub/LargeMotor2/CPL: C5.1, U1.14 (CPL)
/MotorHub/LargeMotor2/DLED: D2.2 (A), R2.1
/MotorHub/LargeMotor2/ELED: D3.2 (A), R4.1
/MotorHub/LargeMotor2/FLED: D4.2 (A), R6.2
/MotorHub/LargeMotor2/FLT: D4.1 (K), U1.4 (~FAULT)
/MotorHub/LargeMotor2/OUTA: J20.1, U1.8 (OUT1)
/MotorHub/LargeMotor2/OUTB: J20.2, U1.10 (OUT2)
/MotorHub/LargeMotor2/VCP: C4.2, U1.12 (VCP)
/MotorHub/LargeMotor2/VREF: C3.1, R3.1, U1.5 (VREF)
/MotorHub/PH2: R2.2, U1.2 (PH/IN2); also elsewhere on the board
/MotorHub/SL2: R4.2, U1.3 (~SLEEP); also elsewhere on the board
GND: C2.2, C3.2, C13.2, C57.2, D2.1 (K), D3.1 (K), R5.1, U1.7 (IMODE), U1.9 (PGND), U1.15 (GND), U1.16 (PMODE), U1.17 (PAD); also elsewhere on the board
VDD: C2.1, C4.1, C13.1, C57.1, U1.11 (VM); also elsewhere on the board

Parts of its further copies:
C14, C16, C19, C21, C24, C26, C66, C68: 100n; C_0402_1005Metric; LCSC C307331
C15, C20, C25, C67: 2u2; C_0402_1005Metric; LCSC C12530
C17, C22, C27, C69: 22n; C_0402_1005Metric; LCSC C1532
C58, C59, C60, C61, C62, C63, C64, C65: 22u; C_0805_2012Metric; LCSC C45783
D5, D8, D11, D26: WLED; LED_0603_1608Metric; LCSC C2290
D6, D9, D12, D27: GLED; LED_0603_1608Metric; LCSC C72043
D7, D10, D13, D28: RLED; LED_0603_1608Metric; LCSC C2286
J26, J27, J28, J29: Screw_Terminal_01x02; TerminalBlock_Phoenix_MKDS-1,5-2_1x02_P5.00mm_Horizontal; LCSC C8404; not fitted
R9, R10, R11, R12, R13, R14, R15, R16, R17, R18, R19, R20, R21, R22, R23, R59, R60, R61, R62, R63: 1k; R_0402_1005Metric; LCSC C11702
U4, U5, U6, U30: DRV8874PWPR; HTSSOP-16-1EP_4.4x5mm_P0.65mm_EP3.4x5mm_Mask2.46x2.31mm; LCSC C1855818

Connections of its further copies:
+3V3: R13.1, R18.1, R23.1, R63.1; also elsewhere on the board
/MotorHub/CR1: R60.2; also elsewhere on the board
/MotorHub/CR3: R10.2; also elsewhere on the board
/MotorHub/CR4: R15.2; also elsewhere on the board
/MotorHub/CR5: R20.2; also elsewhere on the board
/MotorHub/EN1: U30.1 (EN/IN1); also elsewhere on the board
/MotorHub/EN3: U4.1 (EN/IN1); also elsewhere on the board
/MotorHub/EN4: U5.1 (EN/IN1); also elsewhere on the board
/MotorHub/EN5: U6.1 (EN/IN1); also elsewhere on the board
/MotorHub/IR1: R62.2, U30.6 (IROPI); also elsewhere on the board
/MotorHub/IR3: R12.2, U4.6 (IROPI); also elsewhere on the board
/MotorHub/IR4: R17.2, U5.6 (IROPI); also elsewhere on the board
/MotorHub/IR5: R22.2, U6.6 (IROPI); also elsewhere on the board
/MotorHub/LargeMotor1/CPH: C69.2, U30.13 (CPH)
/MotorHub/LargeMotor1/CPL: C69.1, U30.14 (CPL)
/MotorHub/LargeMotor1/DLED: D26.2 (A), R59.1
/MotorHub/LargeMotor1/ELED: D27.2 (A), R61.1
/MotorHub/LargeMotor1/FLED: D28.2 (A), R63.2
/MotorHub/LargeMotor1/FLT: D28.1 (K), U30.4 (~FAULT)
/MotorHub/LargeMotor1/OUTA: J29.1, U30.8 (OUT1)
/MotorHub/LargeMotor1/OUTB: J29.2, U30.10 (OUT2)
/MotorHub/LargeMotor1/VCP: C68.2, U30.12 (VCP)
/MotorHub/LargeMotor1/VREF: C67.1, R60.1, U30.5 (VREF)
/MotorHub/LargeMotor3/CPH: C17.2, U4.13 (CPH)
/MotorHub/LargeMotor3/CPL: C17.1, U4.14 (CPL)
/MotorHub/LargeMotor3/DLED: D5.2 (A), R9.1
/MotorHub/LargeMotor3/ELED: D6.2 (A), R11.1
/MotorHub/LargeMotor3/FLED: D7.2 (A), R13.2
/MotorHub/LargeMotor3/FLT: D7.1 (K), U4.4 (~FAULT)
/MotorHub/LargeMotor3/OUTA: J26.1, U4.8 (OUT1)
/MotorHub/LargeMotor3/OUTB: J26.2, U4.10 (OUT2)
/MotorHub/LargeMotor3/VCP: C16.2, U4.12 (VCP)
/MotorHub/LargeMotor3/VREF: C15.1, R10.1, U4.5 (VREF)
/MotorHub/LargeMotor4/CPH: C22.2, U5.13 (CPH)
/MotorHub/LargeMotor4/CPL: C22.1, U5.14 (CPL)
/MotorHub/LargeMotor4/DLED: D8.2 (A), R14.1
/MotorHub/LargeMotor4/ELED: D9.2 (A), R16.1
/MotorHub/LargeMotor4/FLED: D10.2 (A), R18.2
/MotorHub/LargeMotor4/FLT: D10.1 (K), U5.4 (~FAULT)
/MotorHub/LargeMotor4/OUTA: J27.1, U5.8 (OUT1)
/MotorHub/LargeMotor4/OUTB: J27.2, U5.10 (OUT2)
/MotorHub/LargeMotor4/VCP: C21.2, U5.12 (VCP)
/MotorHub/LargeMotor4/VREF: C20.1, R15.1, U5.5 (VREF)
/MotorHub/LargeMotor5/CPH: C27.2, U6.13 (CPH)
/MotorHub/LargeMotor5/CPL: C27.1, U6.14 (CPL)
/MotorHub/LargeMotor5/DLED: D11.2 (A), R19.1
/MotorHub/LargeMotor5/ELED: D12.2 (A), R21.1
/MotorHub/LargeMotor5/FLED: D13.2 (A), R23.2
/MotorHub/LargeMotor5/FLT: D13.1 (K), U6.4 (~FAULT)
/MotorHub/LargeMotor5/OUTA: J28.1, U6.8 (OUT1)
/MotorHub/LargeMotor5/OUTB: J28.2, U6.10 (OUT2)
/MotorHub/LargeMotor5/VCP: C26.2, U6.12 (VCP)
/MotorHub/LargeMotor5/VREF: C25.1, R20.1, U6.5 (VREF)
/MotorHub/PH1: R59.2, U30.2 (PH/IN2); also elsewhere on the board
/MotorHub/PH3: R9.2, U4.2 (PH/IN2); also elsewhere on the board
/MotorHub/PH4: R14.2, U5.2 (PH/IN2); also elsewhere on the board
/MotorHub/PH5: R19.2, U6.2 (PH/IN2); also elsewhere on the board
/MotorHub/SL1: R61.2, U30.3 (~SLEEP); also elsewhere on the board
/MotorHub/SL3: R11.2, U4.3 (~SLEEP); also elsewhere on the board
/MotorHub/SL4: R16.2, U5.3 (~SLEEP); also elsewhere on the board
/MotorHub/SL5: R21.2, U6.3 (~SLEEP); also elsewhere on the board
GND: C14.2, C15.2, C19.2, C20.2, C24.2, C25.2, C58.2, C59.2, C60.2, C61.2, C62.2, C63.2, C64.2, C65.2, C66.2, C67.2, D5.1 (K), D6.1 (K), D8.1 (K), D9.1 (K), D11.1 (K), D12.1 (K), D26.1 (K), D27.1 (K), R12.1, R17.1, R22.1, R62.1, U4.7 (IMODE), U4.9 (PGND), U4.15 (GND), U4.16 (PMODE), U4.17 (PAD), U5.7 (IMODE), U5.9 (PGND), U5.15 (GND), U5.16 (PMODE), U5.17 (PAD), U6.7 (IMODE), U6.9 (PGND), U6.15 (GND), U6.16 (PMODE), U6.17 (PAD), U30.7 (IMODE), U30.9 (PGND), U30.15 (GND), U30.16 (PMODE), U30.17 (PAD); also elsewhere on the board
VDD: C14.1, C16.1, C19.1, C21.1, C24.1, C26.1, C58.1, C59.1, C60.1, C61.1, C62.1, C63.1, C64.1, C65.1, C66.1, C68.1, U4.11 (VM), U5.11 (VM), U6.11 (VM), U30.11 (VM); also elsewhere on the board

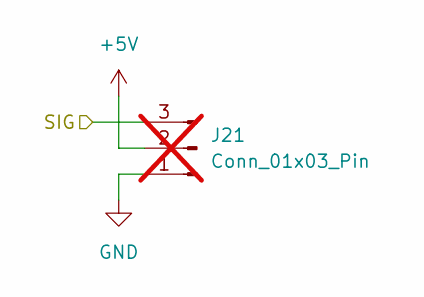
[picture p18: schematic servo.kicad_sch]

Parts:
J21: Conn_01x03_Pin; PinHeader_1x03_P2.54mm_Vertical; LCSC C6332196; not fitted

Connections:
+5V: J21.2; also elsewhere on the board
/MotorHub/SIG1: J21.3; also elsewhere on the board
GND: J21.1; also elsewhere on the board

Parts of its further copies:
J22, J23, J24: Conn_01x03_Pin; PinHeader_1x03_P2.54mm_Vertical; LCSC C6332196; not fitted

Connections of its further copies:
+5V: J22.2, J23.2, J24.2; also elsewhere on the board
/MotorHub/SIG2: J22.3; also elsewhere on the board
/MotorHub/SIG3: J23.3; also elsewhere on the board
/MotorHub/SIG4: J24.3; also elsewhere on the board
GND: J22.1, J23.1, J24.1; also elsewhere on the board

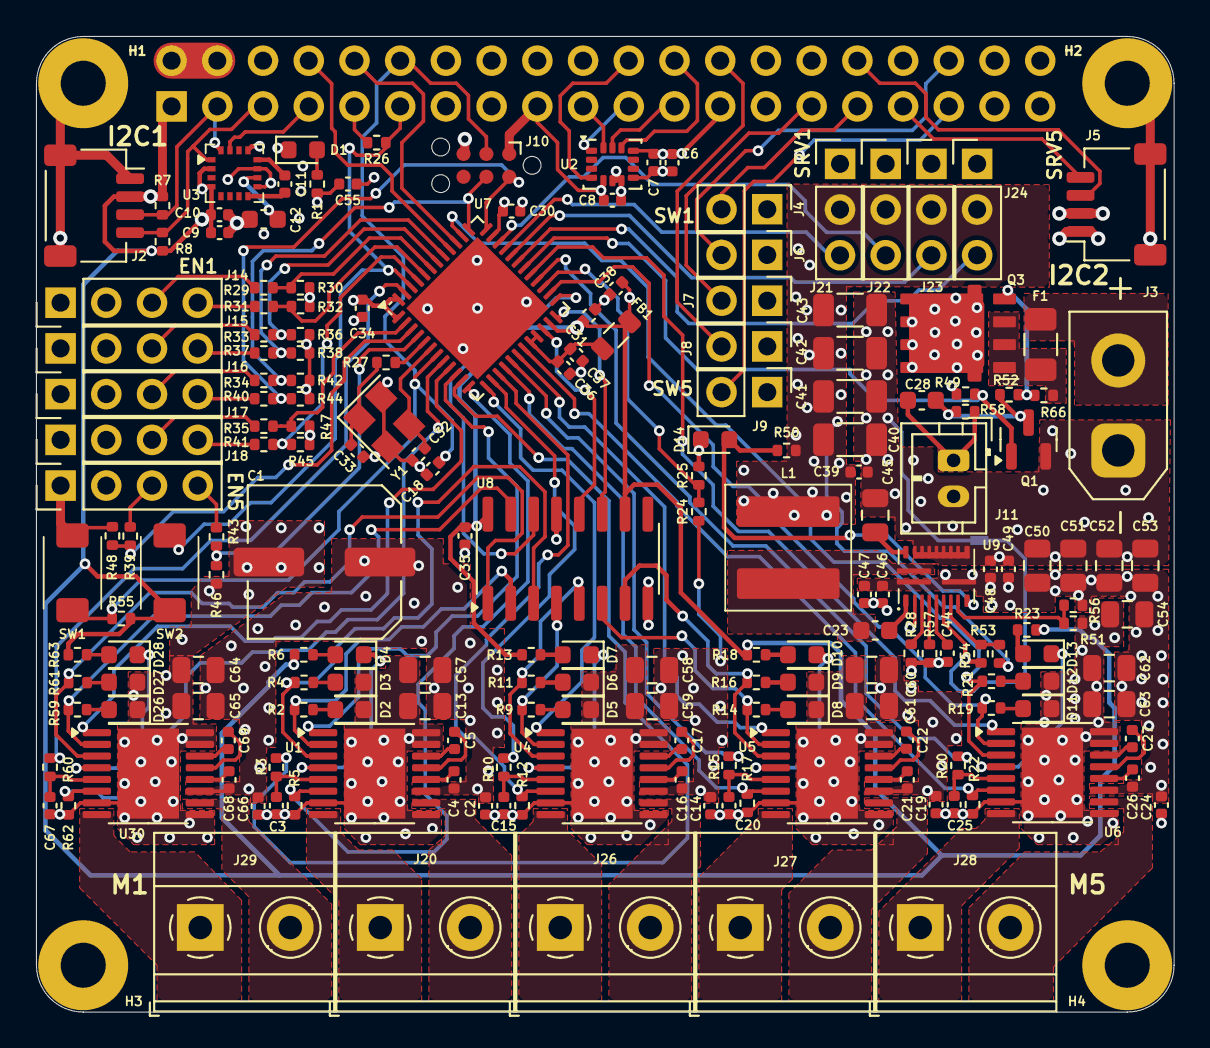
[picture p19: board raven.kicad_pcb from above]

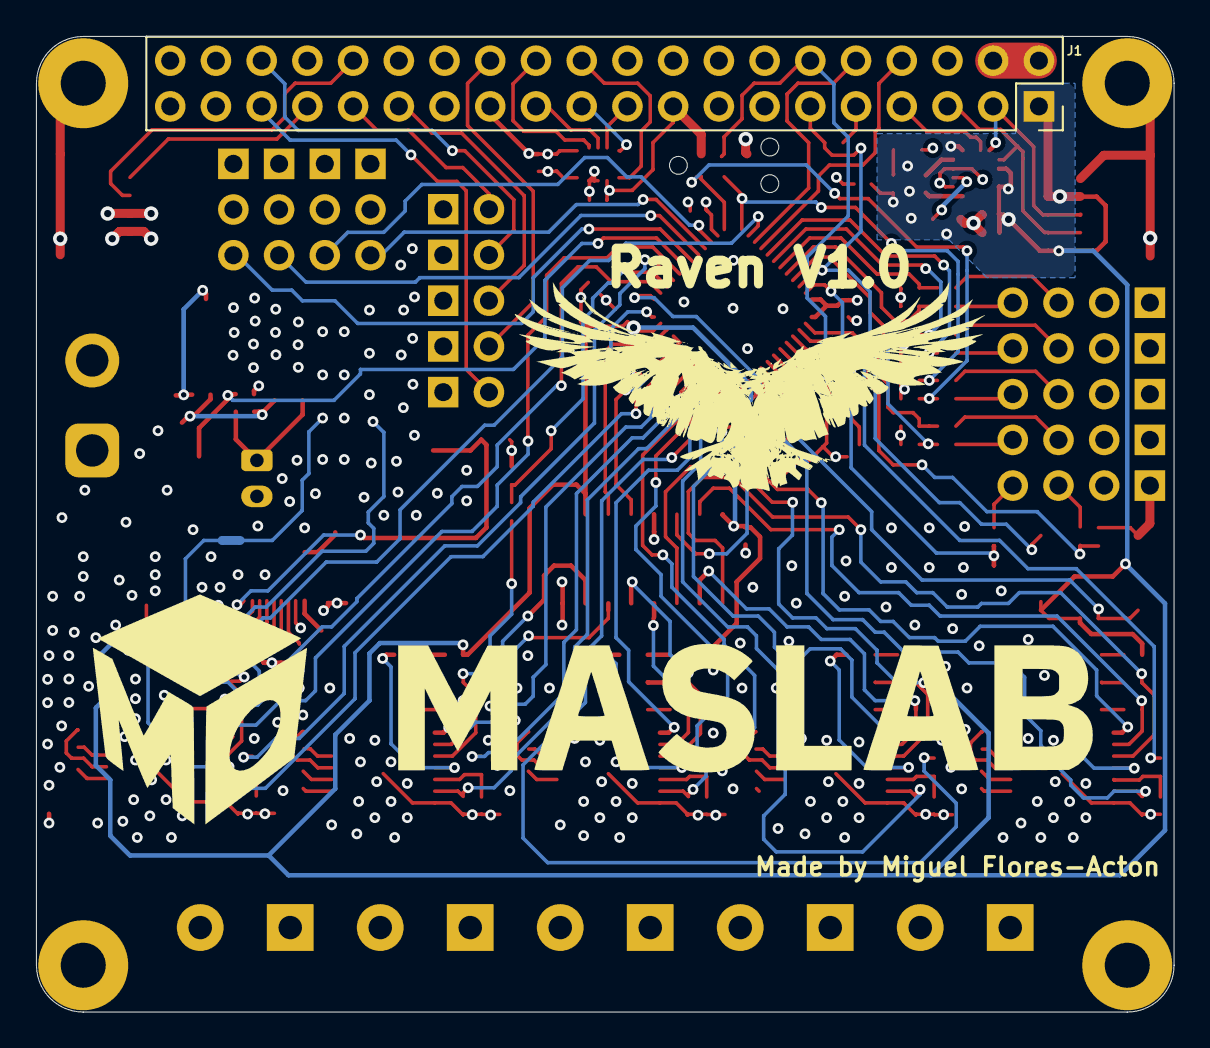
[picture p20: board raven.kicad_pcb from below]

Board: 4 copper layers, 63.2 x 54.2 mm, 198 parts (4 on the bottom side), 150 nets.

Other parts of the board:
G1, G2: LOGO

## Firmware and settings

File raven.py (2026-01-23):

from enum import Enum, unique
from serial import Serial
from serial.tools import list_ports
import struct


class Raven:
    @unique
    class MotorChannel(Enum):
        CH1 = 0
        CH2 = 1
        CH3 = 2
        CH4 = 3
        CH5 = 4

    @unique
    class MotorMode(Enum):
        DISABLE = b"\x00"
        DIRECT = b"\x01"
        POSITION = b"\x02"
        VELOCITY = b"\x03"

    @unique
    class ServoChannel(Enum):
        CH1 = 0
        CH2 = 1
        CH3 = 2
        CH4 = 3

    # Message types
    @unique
    class __MessageType(Enum):
        SERVO_VALUE = 0 << 3
        MOTOR_MODE = 1 << 3
        MOTOR_PID = 2 << 3
        MOTOR_TARGET = 3 << 3
        MOTOR_VOLTAGE = 4 << 3
        MOTOR_CURRENT = 5 << 3
        ENCODER_VALUE = 6 << 3
        MOTOR_VELOCITY_VALUE = 7 << 3  # Read-only
        MOTOR_VOLTAGE_VALUE = 8 << 3  # Read-only
        MOTOR_CURRENT_VALUE = 9 << 3  # Read-only
        ODOMETRY = 10 << 3
        ANGLE = 11 << 3
        BASE = 12 << 3
        RESET = 13 << 3  # Write-only

    @unique
    class __ReadWrite(Enum):
        WRITE = 0x00
        READ = 0x80

    class __RavenSerial:
        """
        /***
        * Message format
        * Start: 1 byte
        *	[7-0] start byte
        * Header: 1 byte
        *	[7] ack
        *	[6-2] length
        *	[1-0] PID (unused)
        * Data: at least 1 byte
        *	header: 1 byte
        *	  [7] 0: read, 1: write
        *	  [6-0] header type
        *	data bytes : any number of bytes
        *	 ...
        * CRC: 1 byte
        *	[7-0] 8-bit CRC
        */
        """

        __START = b"\xAA"

        class CRC8Encoder:
            SMBUS_POLY = 0x07

            def __init__(self, poly=SMBUS_POLY):
                self.__table = list()
                for i in range(256):
                    remainder = i
                    for bit in range(8):
                        if remainder & 0x80:
                            remainder = (remainder << 1) ^ poly
                        else:
                            remainder = remainder << 1
                    self.__table.append(remainder & 0xFF)

            def crc(self, data, start=0):
                remainder = start
                for i in range(len(data)):
                    remainder = self.__table[data[i] ^ remainder]
                return remainder

        def __init__(self, port, baud, timeout=0.001):
            self.__crc = self.CRC8Encoder()
            self.__serial = Serial(port, baud, timeout=timeout)

        def __read(self):
            # Read serial data and return (header, message)
            crc = 0
            message = bytes()
            data = self.__serial.read(1)

            # Start
            if data == self.__START:
                crc = self.__crc.crc(data)
                data = self.__serial.read(1)
            else:
                return None, None

            # Header
            if len(data) == 1:
                crc = self.__crc.crc(data, crc)
                length = (data[0] >> 2) & 0b11111
                data = self.__serial.read(length)
            else:
                return None, None

            # Data:
            if len(data) == length:
                crc = self.__crc.crc(data, crc)
                message = data
                data = self.__serial.read(1)
            else:
                return None, None

            # CRC:
            if len(data) == 1:
                crc = self.__crc.crc(data, crc)
                if crc == 0:
                    return message[0], message[1:]
            return None, None

        def __make_message(self, ack: bool, data: bytes):
            header = len(data) << 2
            if ack:
                header += 0x80  # Set first bit to ack
            message = self.__START + bytes([header]) + data
            crc = self.__crc.crc(message)
            message = message + bytes([crc])
            return message, crc

        def send(self, ack, data, retry=0):
            self.__serial.reset_input_buffer()
            message, crc = self.__make_message(ack, data)
            self.__serial.write(message)

            received_crc, received_data = self.__read()
            if received_crc == crc:
                return received_data
            if retry > 0:
                return self.send(ack, data, retry - 1)
            else:
                return None

    def __init__(self, port: str = None, timeout: float = 0.001):
        """
        Initialize a Raven communication instance
        @port: String of the serial port connected to Raven. Will detect the first open port if not specified.
        @timeout: Serial timeout in second. Default to 1ms
        """
        if port is None:
            port = sorted(list_ports.comports())[0].device
        # Raven has fixed baud at 460800
        self.__serial = Raven.__RavenSerial(port, 460800, timeout)
        self.reset()

    def __del__(self):
        self.reset()

    @staticmethod
    def __make_message(
            message_type: __MessageType,
            rw: __ReadWrite,
            channel: Enum = None,
            data: bytes = bytes(),
    ):
        if channel is None:
            channel_value = 0
        else:
            channel_value = channel.value
        return bytes([message_type.value + rw.value + channel_value]) + data

    def __read_value(
            self,
            message_type: __MessageType,
            channel: Enum = None,
            retry=0,
    ):
        message = Raven.__make_message(
            message_type, Raven.__ReadWrite.READ, channel)
        return self.__serial.send(True, message, retry)

    def __write_value(
            self,
            message_type: __MessageType,
            channel: Enum = None,
            data: bytes = bytes(),
            retry=0,
    ):
        message = Raven.__make_message(
            message_type, Raven.__ReadWrite.WRITE, channel, data
        )
        return self.__serial.send(True, message, retry) is not None

    def get_motor_mode(self, motor_channel: MotorChannel, retry=0):
        """
        Get motor mode
        @motor_channel: Raven.MotorChannel#
        @return: Raven.MotorMode or None if fails
        """
        assert isinstance(motor_channel, Raven.MotorChannel)
        value = self.__read_value(
            Raven.__MessageType.MOTOR_MODE,
            motor_channel,
            retry)
        if value and len(value) == 1:
            for mode in Raven.MotorMode:
                if value == mode.value:
                    return mode
        return None

    def set_motor_mode(
            self, motor_channel: MotorChannel, motor_mode: MotorMode, retry=0
    ):
        """
        Set motor mode to speed or position control
        @motor_channel: Raven.MotorChannel#
        @motor_mode: Raven.MotorMode.SPEED or Raven.MotorMode.POSITION
        @retry: number of retries if command fails
        @return: True if success
        """
        assert isinstance(motor_channel, Raven.MotorChannel)
        return self.__write_value(
            Raven.__MessageType.MOTOR_MODE,
            motor_channel,
            motor_mode.value,
            retry,
        )

    def get_motor_target(self, motor_channel: MotorChannel, retry=0):
        """
        Get motor PID target
        @motor_channel: Raven.MotorChannel#
        @retry: number of retries if command fails
        @return: Motor target (based on set mode) or None if fails
        """
        assert isinstance(motor_channel, Raven.MotorChannel)
        value = self.__read_value(
            Raven.__MessageType.MOTOR_TARGET, motor_channel, retry
        )
        if value and len(value) == 4:
            return struct.unpack("f", value)[0]
        return None

    def set_motor_target(
            self,
            motor_channel: MotorChannel,
            value: float,
            retry=0):
        """
        Set motor PID target
        @motor_channel: Raven.MotorChannel#
        @value: command in encoder count if mode is position or encoder count/sec if mode is velocity
        @retry: number of retries if command fails
        @return: True if success
        """
        assert isinstance(motor_channel, Raven.MotorChannel)
        return self.__write_value(
            Raven.__MessageType.MOTOR_TARGET,
            motor_channel,
            struct.pack("f", value),
            retry,
        )

    __MOTOR_MAX_VALUE = 4095
    __MOTOR_MAX_VALUE_PERCENT = __MOTOR_MAX_VALUE / 100.0
    __MOTOR_MAX_PERCENT_VALUE = 1.0 / __MOTOR_MAX_VALUE_PERCENT

    def set_motor_speed_factor(
            self,
            motor_channel: MotorChannel,
            percent: float,
            reverse=False,
            retry=0):
        """
        Set motor speed factor (percent of battery voltage)
        @motor_channel: Raven.MotorChannel#
        @percent: percent of max speed
        @retry: number of retries if command fails
        @return: True if success
        """
        assert isinstance(motor_channel, Raven.MotorChannel)
        assert percent <= 100 and percent >= 0
        value = int(percent * Raven.__MOTOR_MAX_VALUE_PERCENT)
        if reverse:
            value = -value
        return self.__write_value(
            Raven.__MessageType.MOTOR_VOLTAGE,
            motor_channel,
            struct.pack("h", value),
            retry,
        )

    def set_motor_torque_factor(
            self, motor_channel: MotorChannel, percent: float, retry=0
    ):
        """
        Set motor torque factor (percent of max current = 6.5 A)
        Effectively the same as set_motor_max_current
        @motor_channel: Raven.MotorChannel#
        @percent: percent of max torque
        @retry: number of retries if command fails
        @return: True if success
        """
        assert isinstance(motor_channel, Raven.MotorChannel)
        assert percent <= 100 and percent >= 0
        value = int(percent * Raven.__MOTOR_MAX_VALUE_PERCENT)
        return self.__write_value(
            Raven.__MessageType.MOTOR_CURRENT,
            motor_channel,
            struct.pack("H", value),
            retry,
        )

    __MOTOR_MAX_CURRENT = 6.5

    def set_motor_max_current(
            self, motor_channel: MotorChannel, current: float, retry=0
    ):
        """
        Set motor maximum current (up to 6.5 A).
        Effectively the same as set_motor_torque_factor
        @motor_channel: Raven.MotorChannel#
        @current: Maximum current in A
        @retry: number of retries if command fails
        @return: True if success
        """
        assert current >= 0 and current < Raven.__MOTOR_MAX_CURRENT
        return self.set_motor_torque_factor(
            motor_channel, current / Raven.__MOTOR_MAX_CURRENT * 100.0, retry
        )

    __PID_FREQ = 1000  # Raven PID frequency
    __PID_DT = 1 / __PID_FREQ

    def get_motor_pid(self, motor_channel: MotorChannel, retry=0):
        """
        Get motor PID gain
        @motor_channel: Raven.MotorChannel#
        @retry: number of retries if command fails
        @return: (P,I,D,Percent) values or None if fails
        """
        assert isinstance(motor_channel, Raven.MotorChannel)
        value = self.__read_value(
            Raven.__MessageType.MOTOR_PID, motor_channel, retry)
        if value and len(value) == 16:
            p, i, d, sat = struct.unpack("ffff", value)
            return (
                p,
                i * Raven.__PID_FREQ,
                d * Raven.__PID_DT,
                sat * Raven.__MOTOR_MAX_PERCENT_VALUE,
            )
        return None

    def set_motor_pid(
            self,
            motor_channel: MotorChannel,
            p_gain: float,
            i_gain: float,
            d_gain: float,
            percent: float = 100,
            retry=0,
    ):
        """
        Set motor PID gain
        @motor_channel: Raven.MotorChannel#
        @p_gain: P gain value
        @i_gain: I gain value
        @d_gain: D gain value
        @percent: Percent of effort (reduce speed)
        @retry: number of retries if command fails
        @return: True if success
        """
        assert percent <= 100 and percent >= 0
        sat = float(percent * Raven.__MOTOR_MAX_VALUE_PERCENT)
        return self.__write_value(
            Raven.__MessageType.MOTOR_PID,
            motor_channel,
            struct.pack(
                "ffff",
                p_gain,
                i_gain * Raven.__PID_DT,
                d_gain * Raven.__PID_FREQ,
                sat,
            ),
            retry,
        )

    __SERVO_COUNT_PER_US = 168 / 51  # From raven firmware

    @staticmethod
    def __deg_to_count(deg, min_us=1000, max_us=2000):
        us_range = max_us - min_us
        us = ((deg + 90) / 180 * us_range) + min_us
        return int(us * Raven.__SERVO_COUNT_PER_US)

    @staticmethod
    def __count_to_deg(count, min_us=1000, max_us=2000):
        us_range = max_us - min_us
        us = count / Raven.__SERVO_COUNT_PER_US
        return (us - min_us) / us_range * 180 - 90

    def get_servo_position(
            self,
            servo_channel: ServoChannel,
            min_us=1000,
            max_us=2000,
            retry=0,
    ):
        """
        Get servo position in degree
        @servo_channel: Raven.ServoChannel#
        @min_us: servo's minimum pulse in microsecond
        @max_us: servo's maximum pulse in microsecond
        @retry: number of retries if command fails
        @return: servo position in degree or None if fails
        """
        assert isinstance(servo_channel, Raven.ServoChannel)

        value = self.__read_value(
            Raven.__MessageType.SERVO_VALUE,
            servo_channel,
            retry,
        )

        if value and len(value) == 2:
            count = struct.unpack("H", value)[0]
            return Raven.__count_to_deg(count, min_us, max_us)

    def set_servo_position(
            self,
            servo_channel: ServoChannel,
            degree: float,
            min_us=1000,
            max_us=2000,
            retry=0,
    ):
        """
        Set servo position in degree
        @servo_channel: Raven.ServoChannel#
        @degree: -90 to 90
        @min_us: servo's minimum pulse in microsecond
        @max_us: servo's maximum pulse in microsecond
        @retry: number of retries if command fails
        @return: True if success
        """
        assert isinstance(servo_channel, Raven.ServoChannel)
        if degree < -90 or degree > 90:
            return ValueError("Invalid degree")

        return self.__write_value(
            Raven.__MessageType.SERVO_VALUE,
            servo_channel,
            struct.pack("H", Raven.__deg_to_count(degree, min_us, max_us)),
            retry,
        )

    def set_servo_off(self, servo_channel: ServoChannel, retry=0):
        """
        Turn off servo
        @servo_channel: Raven.ServoChannel#
        @retry: number of retries if command fails
        @return: True if success
        """
        self.__write_value(
            Raven.__MessageType.SERVO_VALUE,
            servo_channel,
            struct.pack("H", 0),
            retry,
        )

    def get_motor_encoder(self, motor_channel: MotorChannel, retry=0):
        """
        Get motor encoder count
        @motor_channel: Raven.MotorChannel#
        @retry: number of retries if command fails
        @return: number of encoder count or None if fails
        """
        assert isinstance(motor_channel, Raven.MotorChannel)
        value = self.__read_value(
            Raven.__MessageType.ENCODER_VALUE, motor_channel, retry
        )
        if value and len(value) == 4:
            return struct.unpack("i", value)[0]
        return None

    def set_motor_encoder(
            self,
            motor_channel: MotorChannel,
            value: int,
            retry=0):
        """
        Set motor encoder count
        @motor_channel: Raven.MotorChannel#
        @value: new value for encoder
        @retry: number of retries if command fails
        @return: number of encoder count or None if fails
        """
        assert isinstance(motor_channel, Raven.MotorChannel)
        return self.__write_value(
            Raven.__MessageType.ENCODER_VALUE,
            motor_channel,
            struct.pack("i", int(value)),
            retry,
        )

    def get_motor_velocity(self, motor_channel: MotorChannel, retry=0):
        """
        Set motor encoder count
        @motor_channel: Raven.MotorChannel#
        @retry: number of retries if command fails
        @return: number of encoder count per second or None if fails
        """
        assert isinstance(motor_channel, Raven.MotorChannel)
        value = self.__read_value(
            Raven.__MessageType.MOTOR_VELOCITY_VALUE, motor_channel, retry
        )
        if value and len(value) == 4:
            return struct.unpack("f", value)[0]
        return None

    def set_odometry(self, x, y, retry=0):
        return self.__write_value(Raven.__MessageType.ODOMETRY,
                                  data=struct.pack("ff", x, y),
                                  retry=retry)

    def get_odometry(self, retry=0):
        value = self.__read_value(
            Raven.__MessageType.ODOMETRY, retry=retry
        )
        if value and len(value) == 8:
            x, y = struct.unpack("ff", value)
            return x, y
        return None

    def set_angle(self, angle: float, retry=0):
        return self.__write_value(Raven.__MessageType.ANGLE,
                                  data=struct.pack("f", float(angle)),
                                  retry=retry)

    def get_angle(self, retry=0):
        value = self.__read_value(
            Raven.__MessageType.ANGLE, retry=retry
        )
        if value and len(value) == 4:
            return struct.unpack("f", value)[0]
        return None

    def set_base(self, wheel_d, base_d, retry=0):
        return self.__write_value(Raven.__MessageType.BASE,
                                  data=struct.pack("ff", wheel_d, base_d),
                                  retry=retry)

    def get_base(self, retry=0):
        value = self.__read_value(
            Raven.__MessageType.BASE, retry=retry
        )
        if value and len(value) == 8:
            wheel_d, base_d = struct.unpack("ff", value)
            return wheel_d, base_d
        return None

    def reset(self, retry=0):
        """
        Reset all motors' mode to DISABLE, all encoder readings to 0, all PID gains to 0
        """
        return self.__write_value(Raven.__MessageType.RESET, retry=retry)


if __name__ == "__main__":
    import time

    raven = Raven()

    # Velocity test

    channel1 = Raven.MotorChannel.CH1
    channel3 = Raven.MotorChannel.CH3

    # raven.set_motor_mode(channel1, Raven.MotorMode.VELOCITY)
    # raven.set_motor_mode(channel3, Raven.MotorMode.VELOCITY)
    # raven.set_motor_torque_factor(channel1, 10)
    # raven.set_motor_max_current(channel3, 1.5)
    # raven.set_motor_pid(channel1, 0, 5, 1, 25)
    # raven.set_motor_pid(channel3, 0, 5, 1, 25)
    # print(raven.get_motor_pid(channel3))
    # raven.set_motor_target(channel1, -4000)
    # raven.set_motor_target(channel3, 2300)

    # raven.set_motor_mode(channel1, Raven.MotorMode.DIRECT)
    # raven.set_motor_mode(channel3, Raven.MotorMode.DIRECT)
    # raven.set_motor_torque_factor(channel1, 100)
    # raven.set_motor_torque_factor(channel3, 100)
    # raven.set_motor_speed_factor(channel1, 100, reverse=True)
    # raven.set_motor_speed_factor(channel3, 100, reverse=False)

    raven.set_motor_mode(channel1, Raven.MotorMode.POSITION)
    raven.set_motor_mode(channel3, Raven.MotorMode.POSITION)
    raven.set_motor_torque_factor(channel1, 10)
    raven.set_motor_max_current(channel3, 1.5)
    raven.set_motor_pid(channel1, 30, 10, 2, 50)
    raven.set_motor_pid(channel3, 30, 10, 2, 50)
    print(raven.get_motor_pid(channel3))
    raven.set_motor_target(channel1, -640)
    raven.set_motor_target(channel3, 640)

    current_time = time.time()
    current_encoder = raven.get_motor_encoder(channel3)
    while True:
        try:
            new_time = time.time()
            new_encoder = raven.get_motor_encoder(channel3)
            raven_vel = raven.get_motor_velocity(channel3)
            cal_vel = (new_encoder - current_encoder) / \
                (new_time - current_time)
            print("Raven Ecd:", new_encoder)
            print("Raven Vel:", raven_vel)
            print("Calc Vel: ", cal_vel)
            print("Diff:", raven_vel - cal_vel)
            current_time = new_time
            current_encoder = new_encoder
            time.sleep(0.1)
        except BaseException:
            # raven.set_motor_mode(channel1, Raven.MotorMode.DISABLE)
            # raven.set_motor_mode(channel3, Raven.MotorMode.DISABLE)
            time.sleep(1)
            break

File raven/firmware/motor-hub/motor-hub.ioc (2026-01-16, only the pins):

Mcu.UserName=STM32G431CBUx
PA0.Signal=ADC1_IN1
PA1.Signal=S_TIM2_CH2
PA10.Signal=S_TIM1_CH3
PA11.Signal=S_TIM1_CH4
PA12.Signal=S_TIM16_CH1
PA13.GPIO_Label=B3
PA13.Signal=GPIO_Input
PA14.GPIO_Label=A3
PA14.Signal=GPIO_Input
PA15.GPIO_Label=SL5
PA15.Signal=GPIO_Output
PA2.Signal=S_TIM2_CH3
PA3.Signal=S_TIM2_CH4
PA4.Signal=ADC2_IN17
PA5.Signal=S_TIM2_CH1
PA6.Signal=S_TIM3_CH1
PA7.Signal=ADC2_IN4
PA8.GPIO_Label=PWR
PA8.Signal=GPIO_Output
PA9.Signal=S_TIM1_CH2
PB0.Signal=S_TIM3_CH3
PB1.Signal=S_TIM3_CH4
PB10.GPIO_Label=RSV
PB10.Signal=GPIO_Output
PB11.GPIO_Label=RCLK
PB11.Signal=GPIO_Output
PB12.GPIO_Label=RDAT
PB12.Signal=GPIO_Output
PB13.GPIO_Label=PH5
PB13.Signal=GPIO_Output
PB14.Signal=ADC1_IN5
PB15.Signal=S_TIM15_CH2
PB2.Signal=ADC2_IN12
PB3.GPIO_Label=B2
PB3.Signal=GPIO_Input
PB4.GPIO_Label=A2
PB4.Signal=GPIO_Input
PB5.GPIO_Label=A1
PB5.Signal=GPIO_Input
PB6.GPIO_Label=B1
PB6.Signal=GPIO_Input
PB7.GPIO_Label=B4
PB7.Signal=GPIO_Input
PB9.Signal=S_TIM4_CH4
PC10.Signal=USART3_TX
PC11.Signal=USART3_RX
PC13.GPIO_Label=A4
PC13.Signal=GPIO_Input
PC14-OSC32_IN.GPIO_Label=A5
PC14-OSC32_IN.Signal=GPIO_Input
PC15-OSC32_OUT.GPIO_Label=B5
PC15-OSC32_OUT.Signal=GPIO_Input
PC4.Signal=ADC2_IN5
PC6.Signal=S_TIM8_CH1
PF0-OSC_IN.Signal=RCC_OSC_IN
PF1-OSC_OUT.Signal=RCC_OSC_OUT

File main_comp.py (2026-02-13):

import time
import argparse
import threading
from connection.ComputerReceiver import ComputerReceiver
from InputProcessor import InputProcessor
from connection.FrameSaver import FrameSaver
from connection.frame_info import FrameInfo
from vision.zone_utils import visualize_xy_locations, visualize_convex_hulls
from vision.relativeCoordinates import world_to_relative
from colors import GREEN_ZONE, RED_ZONE, GOLDEN_ZONE, GREEN_ZONE_OPP, RED_ZONE_OPP, GOLDEN_ZONE_OPP
from RobotHandler import RobotHandler
from profiler import Profiler
import config


def main():
    # ----------------- GET INPUTS -----------------
    parser = argparse.ArgumentParser(description="Computer Video Receiver")
    parser.add_argument("--host", default="0.0.0.0",
                        help="Host to bind to (default: 0.0.0.0)")
    parser.add_argument("--video-port", type=int, default=config.VIDEO_PORT,
                        help=f"Video port (default: {config.VIDEO_PORT})")
    parser.add_argument(
        "--coord-port",
        type=int,
        default=config.COMMAND_PORT,
        help=f"Coordinate port (default: {config.COMMAND_PORT})")
    parser.add_argument("--no-display", action="store_true",
                        help="Disable video display")
    parser.add_argument(
        "--picture-delay",
        type=float,
        default=None,
        help="Delay in seconds between saving pictures (default: don't save)")
    args = parser.parse_args()

    window_name_top = "Top Camera"
    window_name_bottom = "Bottom Camera"

    # ----------------- CREATE RECEIVER AND PROCESSORS -----------------
    computer_receiver = ComputerReceiver(
        args.host, args.video_port, args.coord_port)

    # Get robot commander for sending commands
    robot_commander = computer_receiver.commander

    robotHandler = RobotHandler(robot_commander)
    inputProcessor = InputProcessor(
        robot_commander, window_name_top, robotHandler)

    # Only create FrameSaver if picture-delay is specified
    frame_saver = None
    if args.picture_delay is not None:
        frame_saver = FrameSaver(args.picture_delay, "images")

    # Create main profiler for frame processing pipeline
    main_profiler = Profiler(False)

    def process(frame_info: FrameInfo) -> None:
        # Process frame using FrameInfo
        main_profiler.start_frame()
        robotHandler.handleFrame(frame_info)
        main_profiler.record("robotHandler")

        # Only save frame if frame_saver was initialized
        if frame_saver is not None:
            frame_saver.saveFrame(frame_info)
            main_profiler.record("saveFrame")

        # Overlay YOLO segmentation results on frames first
        if robotHandler.result_top is not None:
            if robotHandler.result_top.masks is not None and len(
                    robotHandler.result_top.masks) > 0:
                # Plot segmentation masks on top frame
                frame_info.frame_top = robotHandler.result_top.plot(
                    boxes=True,
                    masks=True,
                    conf=True,
                    line_width=2,
                    labels=True
                )
                # Overlay convex hulls in cyan
                frame_info.frame_top = visualize_convex_hulls(
                    frame_info.frame_top,
                    robotHandler.result_top,
                    color=(255, 255, 0),  # Cyan
                    thickness=2
                )

        if robotHandler.result_bottom is not None:
            if robotHandler.result_bottom.masks is not None and len(
                    robotHandler.result_bottom.masks) > 0:
                # Plot segmentation masks on bottom frame
                frame_info.frame_bottom = robotHandler.result_bottom.plot(
                    boxes=True,
                    masks=True,
                    conf=True,
                    line_width=2,
                    labels=True
                )
                # Overlay convex hulls in cyan
                frame_info.frame_bottom = visualize_convex_hulls(
                    frame_info.frame_bottom,
                    robotHandler.result_bottom,
                    color=(255, 255, 0),  # Cyan
                    thickness=2
                )

        main_profiler.record("segmentation_viz")

        # Now add custom visualizations on top of segmentations
        # Visualize can locations on frames
        if len(robotHandler.cans) > 0:
            # Convert world coordinates to camera-relative coordinates
            can_locations_relative = [
                world_to_relative(can, robotHandler.robot_pose)
                for can in robotHandler.cans
            ]

            # Visualize on top camera
            frame_info.frame_top = visualize_xy_locations(
                frame_info.frame_top,
                can_locations_relative,
                robotHandler.robot_pose,
                is_top=True,
                color=(0, 255, 255),  # Yellow for cans
                radius=8,
                labels=[f"C{i}" for i in range(len(robotHandler.cans))]
            )

            # Visualize on bottom camera
            frame_info.frame_bottom = visualize_xy_locations(
                frame_info.frame_bottom,
                can_locations_relative,
                robotHandler.robot_pose,
                is_top=False,
                color=(0, 255, 255),  # Yellow for cans
                radius=8,
                labels=[f"C{i}" for i in range(len(robotHandler.cans))]
            )

        # # Visualize zone polygons
        # zone_colors = {
        #     GREEN_ZONE: (0, 255, 0),      # Green
        #     RED_ZONE: (0, 0, 255),        # Red
        #     GOLDEN_ZONE: (0, 215, 255),   # Gold
        #     GREEN_ZONE_OPP: (100, 200, 100),   # Light green
        #     RED_ZONE_OPP: (100, 100, 200),     # Light red
        #     GOLDEN_ZONE_OPP: (100, 215, 255)   # Light gold
        # }
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

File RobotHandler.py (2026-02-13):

import math
import numpy as np
from enum import Enum, auto
from typing import Tuple, List
from spatialmath import SE2
from IRobotCommander import IRobotCommander  # type: ignore
from connection.frame_info import FrameInfo
from navHelpers import get_rotate
from vision.segment import segmentImage
from vision.can_utils import getCans
from vision.relativeCoordinates import relative_to_world, world_to_relative
from profiler import Profiler
from thetaStar import ThetaStar
from streamer import Streamer
from config import FPS, CAN_DIAMETER, ROBOT_DIAMETER, APPROACH_OFFSET
from colors import GREEN_ZONE, RED_ZONE, GOLDEN_ZONE, GREEN_CAN, RED_CAN, GOLDEN_CAN, canNamesToNumbers


class RobotState(Enum):
    SearchForCan = auto()
    MoveToCan = auto()
    ApproachingCan = auto()
    PickupCan = auto()
    MoveToZone = auto()
    Done = auto()
    AfterApproaching = auto()


class RobotHandler:
    """Simplified robot handler with basic can collection strategy."""

    # Constants
    def __init__(self, robot_commander: IRobotCommander):
        self.state = RobotState.SearchForCan
        self.started = False
        self.paused = False
        self.waiting_for_command_id = 0

        # Configuration
        self.MAX_STACK = 2  # Number of cans to collect
        self.cans_collected = 0  # Total cans delivered to zone
        self.cans_held = 0  # Number of cans currently holding
        self.target_zone = GREEN_ZONE
        self.target_can_color = RED_CAN  # Color of cans to search for

        # Memory
        # Hardcoded zone centers for testing
        self.zones: list[Tuple[float, float]] = [(0, 0)] * 3
        # HERE
        self.zones[GREEN_ZONE] = (1000, 0)
        self.zones[RED_ZONE] = (990, -939.8)
        self.zones[GOLDEN_ZONE] = (2235, -914)
        self.cans: List[Tuple[float, float]] = []
        self.can_colors: List[int] = []
        self.can_detections: dict[Tuple[int, int], int] = {}
        self.DETECTION_THRESHOLD = 3

        # Current state
        self.current_can: Tuple[float, float, int] = (0, 0, -1)
        self.claw_raised = True
        self.can_in_gripper = False

        # Robot components
        self.robot_commander = robot_commander
        self.thetaStar = ThetaStar()
        self.profiler = Profiler(False)
        self.telemetry = Streamer()

        # Frame data
        self.frame_top: np.ndarray = np.array([[]])
        self.frame_bottom: np.ndarray = np.array([[]])
        self.frame_id = -1
        self.robot_pose = SE2(0, 0, 0)

        # Segmentation results
        self.result_top = None
        self.result_bottom = None

        self.telemetry.set_data(self.get_picklable_dict())

        self.cans_collected = 0
        self.cans_held = 0
        self.claw_raised = True
        self.can_in_gripper = False
        self.state = RobotState.SearchForCan

    def handleFrame(self, frame_info: FrameInfo):
        self.profiler.start_frame()

        # if self.paused:
        #     return
        # self.robot_commander.open_gripper()
        # self.robot_commander.lower_elevator()
        # self.paused = True
        # return

        if (not self.started) or self.paused:
            self.profiler.end_frame()
            return

        # Check if waiting for command
        if self.waiting_for_command_id > 0:
            if frame_info.lastCompletedCommandId >= self.waiting_for_command_id:
                print(f"Command {self.waiting_for_command_id} completed")
                self.waiting_for_command_id = 0
            else:
                self.profiler.end_frame()
                return

        # Update frame data
        self.frame_top = frame_info.frame_top
        self.frame_bottom = frame_info.frame_bottom
        self.frame_id = frame_info.frame_id
        self.robot_pose = SE2(frame_info.x, frame_info.y, frame_info.theta)
        self.distanceSensed = frame_info.distanceSensed
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

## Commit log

2026-01-06 Added yolo
    [model.ncnn.param]
2026-01-07 Add back frame rate
2026-01-10 thread safety for nav
2026-01-10 fixed bugs in nav
    [nav.py]
2026-01-11 path planning from click should work now, changed stuff to tuples to be right type and fixed errors
    [main_comp.py, nav.py]
2026-01-11 fix to start movement recevigin thread
    [config.py, main_comp.py]
2026-01-11 don't try to reconnect pi when failed
    [main_pi.py]
2026-01-11 fixed error in rotation calculations
    [nav.py]
2026-01-11 added movement commander class and fixed angle to be CCW
    [main_comp.py, nav.py]
2026-01-11 thread safety for movement
2026-01-11 fixed bug about getting movement from plan
    [main_comp.py]
2026-01-12 calibration stuff
2026-01-13 added runs
    [results.csv]
2026-01-13 nav changes
    [model.ncnn.param]
2026-01-14 nav merges hopefully it works
    [model.ncnn.param]
2026-01-14 printing navmove and smooth
2026-01-14 calibration stuff, some problems with out of distribution points
2026-01-14 calibration and click to move kinda works
2026-01-16 odometry firmware
    [RWW0021A.STEP, SM04B-SRSS-TB.STEP, XT30PW-M.STEP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]
2026-01-17 Raven (#10)
    * testing odometry
    * odometry fies
    * stuff
    * IMU
    * stuff
    * updated measurements
2026-01-18 fixed imu jerk
2026-01-22 removed print and added spatiamth-python to reqs
2026-01-22 thread safe raven wrapper (probably didn't need this)
    [RavenWrapper.py, config.py, nav.py]
2026-01-23 frame size chosen
2026-02-13 Working (#11)
    * changes more
    * a smal amount of changes
    * cool changes
    * even more changes
    * changes for junhui
    * changes
    * frame size stuff works!
    * split up nav helper functions into another file
    * videoblacktopbot
    * frameinfo
    * cameras
    * frameinfo
    * two camera
    * UNTESTED threaded reading 2 cams
    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
    [model.ncnn.param, results.csv]
